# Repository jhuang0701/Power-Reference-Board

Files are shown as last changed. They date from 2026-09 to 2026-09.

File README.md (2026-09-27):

# 3-Phase FOC BLDC Motor Driver with Onboard IMU

A custom 4-layer PCB for field-oriented control (FOC) of a brushless DC motor, with an onboard IMU for real-time orientation feedback. Designed in KiCad, targeting a self-balancing single-wheel robot or reaction-wheel inverted pendulum as the demo application.

This is a design-only project: schematic and layout are complete and DRC-clean. Fabrication is a separate decision, not yet made.

## What it does

The board takes a 6S battery input (22.2V nominal, up to 25.2V) and drives a 3-phase BLDC motor using field-oriented control, with current feedback and IMU data available for a real-time stabilization loop. It's built around three main subsystems: power delivery and protection, the 3-phase gate drive and half-bridge power stage, and the sensing/control electronics.

## Core components

- **MCU:** STM32G474RET6 (LQFP-64). Chosen specifically for its onboard op-amps, which are used directly for current-sense amplification, and for TIM1's hardware dead-time generation on complementary PWM channels.
- **Gate driver:** DRV8353HRTAT, a 102V-rated 3-phase smart gate driver in hardware-interface mode (no SPI on this variant), configured via resistor-divider pins for 6x independent PWM mode.
- **Phase MOSFETs:** 6x CSD18540Q5BT (60V, 2.2mΩ RDS(on)), two per phase leg.
- **IMU:** ICM-42688-P, 6-axis accelerometer/gyroscope, connected over SPI.
- **Buck converter:** TPS54331DR, steps the battery rail down to a clean 3.3V supply for the MCU and IMU.
- **Reverse-polarity protection:** a 7th CSD18540Q5BT, wired low-side in the ground return path, with a Zener-clamped gate bias network. (An earlier design used a small P-channel MOSFET for this; it was replaced after checking its actual gate-voltage rating against the battery voltage and finding it wouldn't survive.)

## Design decisions worth knowing about

**Dual current-sensing paths.** The DRV8353HRTAT's built-in shunt amplifiers are used only for the driver's own hardware overcurrent protection, independent of the MCU. The actual current feedback used for the FOC control loop comes from the STM32G474's internal op-amps, wired directly to the same shunt resistors. Two separate paths, one fast and hardware-only for protection, one precise and MCU-driven for control.

**Hardware dead-time via TIM1.** Rather than relying on the gate driver's default switching behavior, all six gate signals (INHx/INLx) are driven independently from the MCU's TIM1 timer, which generates dead-time insertion in hardware. This gives direct control over switching behavior rather than trusting a fixed driver-side default.

**Mixed-signal supply isolation.** VDDA (the MCU's analog supply, feeding the ADC and current-sense op-amps) is isolated from the main 3.3V digital rail with a series resistor and its own local decoupling, keeping switching noise out of the current measurements.

## Specs

| | |
|---|---|
| Input | 6S Li-ion, 22.2V nominal / 25.2V max |
| Phase current | 15A continuous, 30A peak |
| Board | 4-layer, 60x60mm, 2oz outer copper |
| MCU | STM32G474RET6 |
| Gate driver | DRV8353HRTAT |
| IMU | ICM-42688-P (SPI) |

## Repo contents

- `/schematic` - full schematic PDF export
- `/gerbers` - fabrication-ready Gerber files
- `/bom` - bill of materials
- `/renders` - 3D board renders and layout screenshots

## Status

Schematic and layout complete, DRC-clean. Fabrication not yet started.

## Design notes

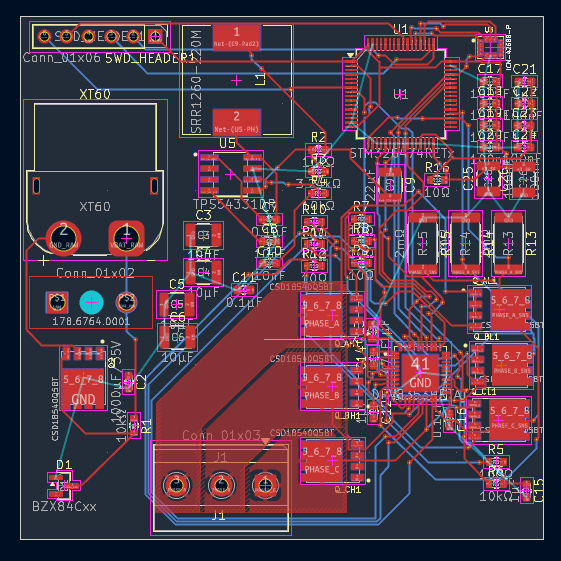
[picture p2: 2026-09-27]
public/project-power-reference-board-2d-view.png

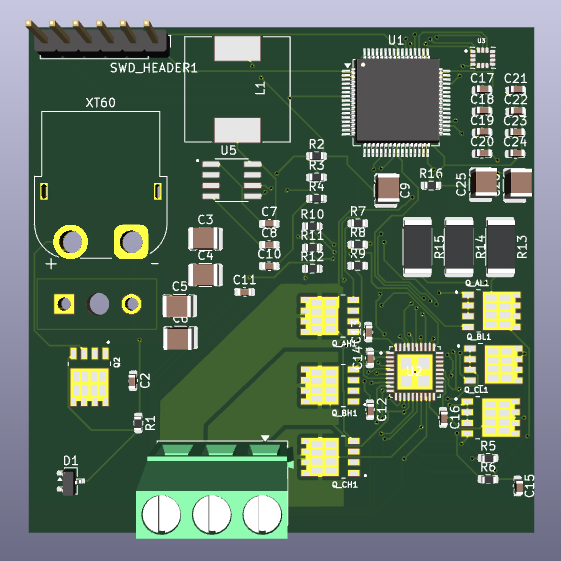
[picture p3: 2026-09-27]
public/project-power-reference-board-3d-view-front.png

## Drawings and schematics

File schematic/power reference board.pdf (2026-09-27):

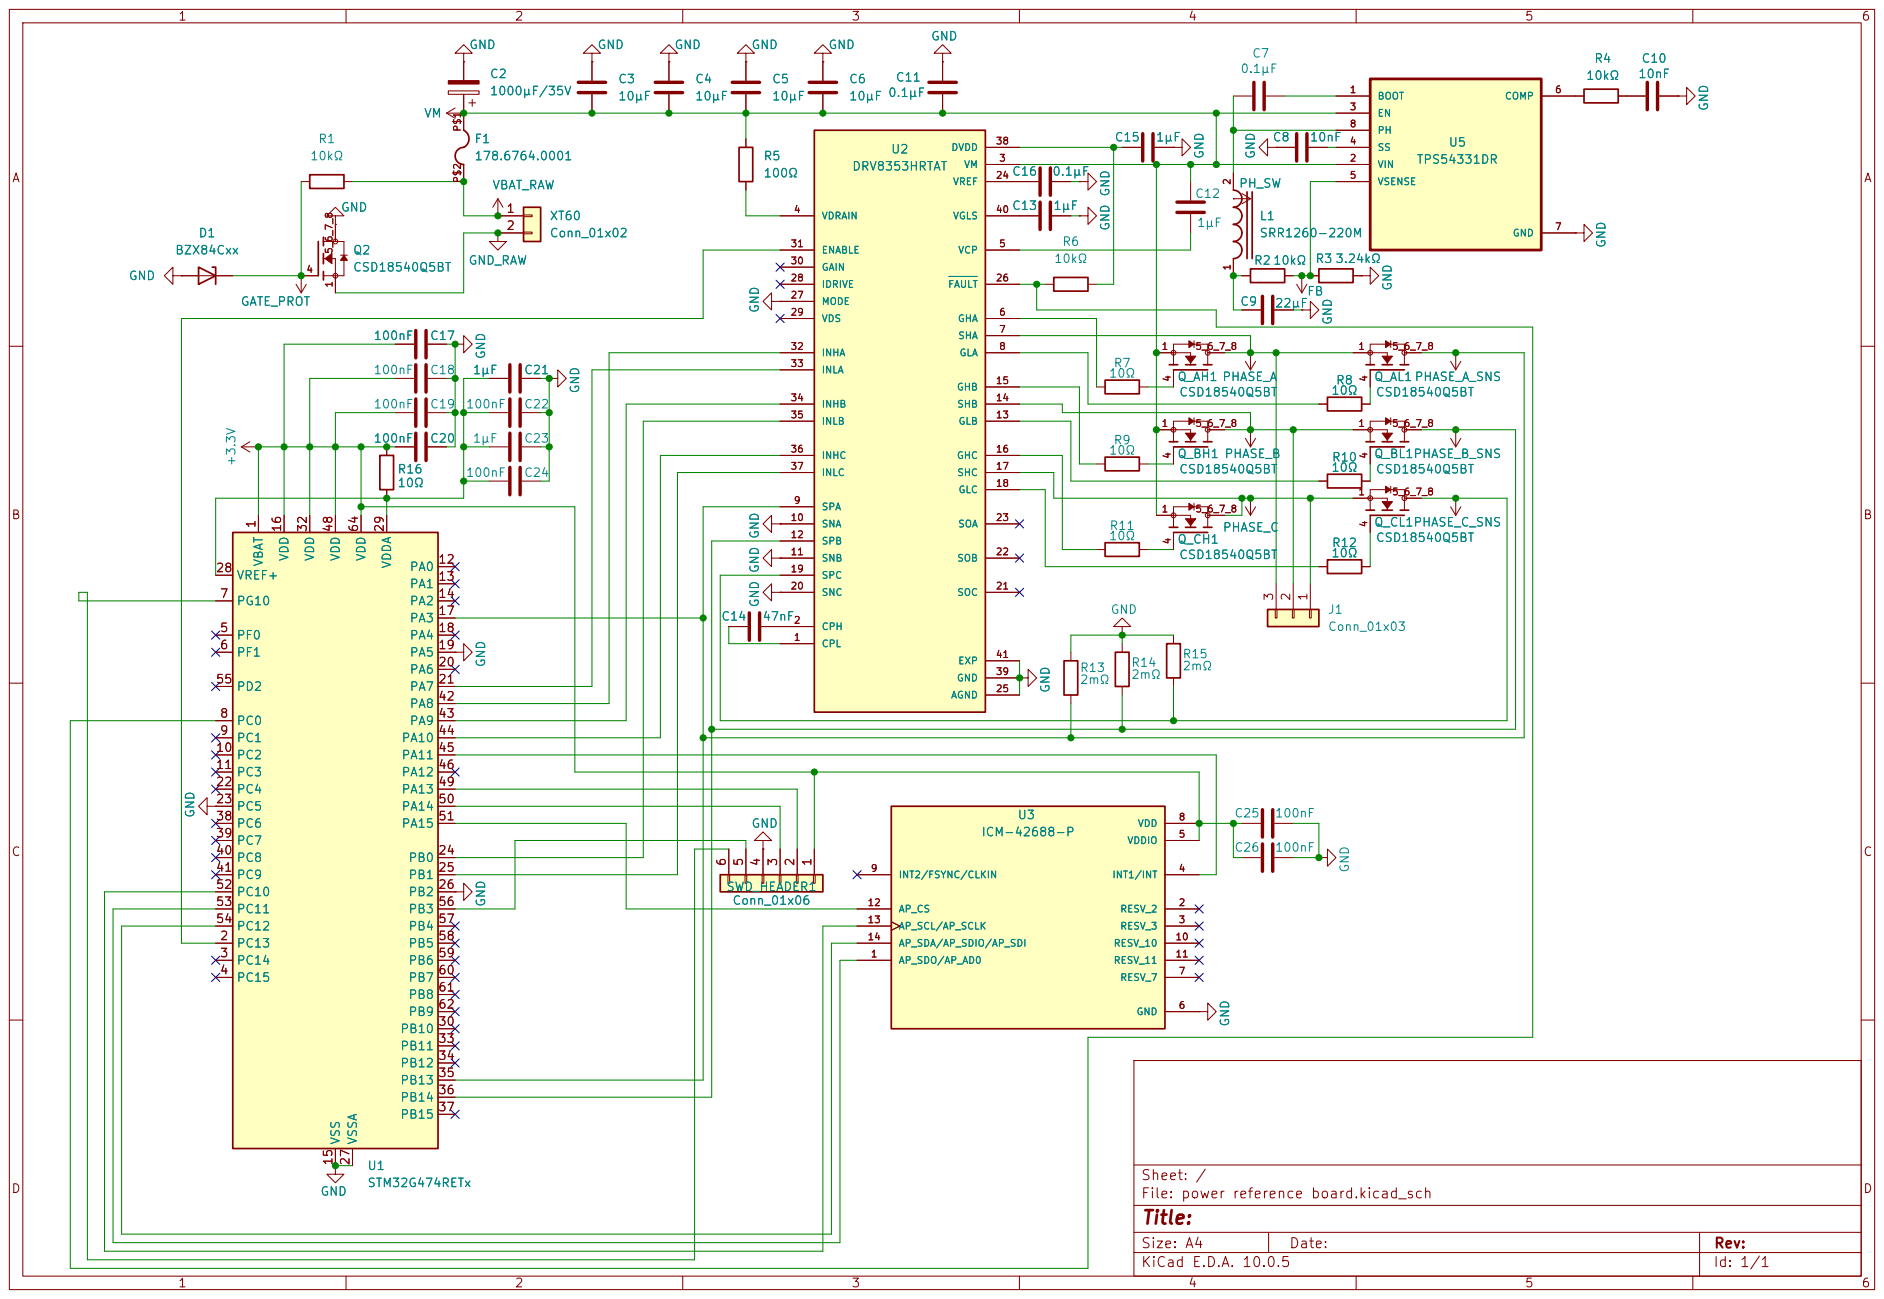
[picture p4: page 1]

Sheet: /
File: power reference board.kicad_sch
Title:

Size: A4 | Rev:
KiCad E.D.A. 10.0.5 | Id: 1/1

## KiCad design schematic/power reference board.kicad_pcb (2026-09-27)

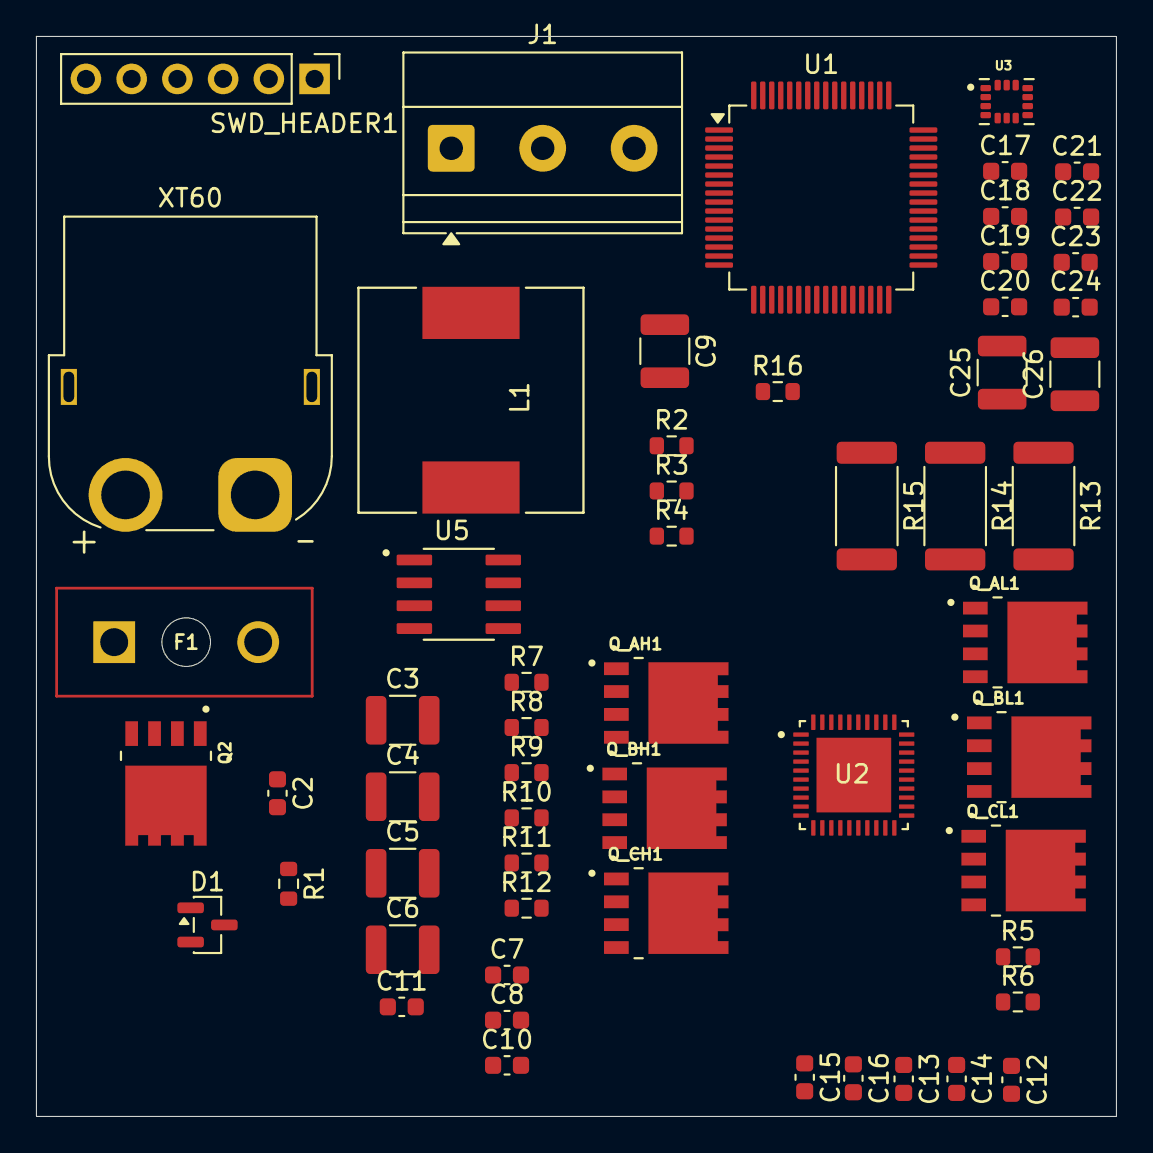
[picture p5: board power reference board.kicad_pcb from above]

Board: 4 copper layers, 60.0 x 60.0 mm, 58 parts (0 on the bottom side), 56 nets, no tracks yet.

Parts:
C2: 1000µF/35V; C_0603_1608Metric
C3, C4, C5, C6: 10µF; C_1210_3225Metric
C7, C11, C16: 0.1µF; C_0603_1608Metric
C8, C10: 10nF; C_0603_1608Metric
C9: 22µF; C_1210_3225Metric
C12, C13, C15, C21, C23: 1µF; C_0603_1608Metric
C14: 47nF; C_0603_1608Metric
C17, C18, C19, C20, C22, C24: 100nF; C_0603_1608Metric
C25, C26: 100nF; C_1210_3225Metric
D1: BZX84Cxx; SOT-23
F1: 178.6764.0001; LITTLEFUSE_178.6764.0001
J1: Conn_01x03; TerminalBlock_Phoenix_MKDS-1,5-3-5.08_1x03_P5.08mm_Horizont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
L1: SRR1260-220M; INDP125125X600N
Q2: CSD18540Q5BT; TRANS_CSD18540Q5BT
Q_AH1: CSD18540Q5BT; TRANS_CSD18540Q5BT
Q_AL1: CSD18540Q5BT; TRANS_CSD18540Q5BT
Q_BH1: CSD18540Q5BT; TRANS_CSD18540Q5BT
Q_BL1: CSD18540Q5BT; TRANS_CSD18540Q5BT
Q_CH1: CSD18540Q5BT; TRANS_CSD18540Q5BT
Q_CL1: CSD18540Q5BT; TRANS_CSD18540Q5BT
R1, R2, R4, R6: 10kΩ; R_0603_1608Metric
R3: 3.24kΩ; R_0603_1608Metric
R5: 100Ω; R_0603_1608Metric
R7, R8, R9, R10, R11, R12, R16: 10Ω; R_0603_1608Metric
R13, R14, R15: 2mΩ; R_2512_6332Metric
SWD_HEADER1: Conn_01x06; PinHeader_1x06_P2.54mm_Vertical
U1: STM32G474RETx; LQFP-64_10x10mm_P0.5mm
U2: DRV8353HRTAT; QFN50P600X600X80-41N
U3: ICM-42688-P; PQFN50P300X250X97-14N
U5: TPS54331DR; SOIC127P599X175-8N
XT60: Conn_01x02; AMASS_XT60PW-F_1x02_P7.20mm_Horizontal

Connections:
+3.3V: C17.2, C18.2, C19.2, C20.2, C25.2, C26.2, R16.2, SWD_HEADER1.1, U1.1 (VBAT), U1.16 (VDD), U1.32 (VDD), U1.48 (VDD), U1.64 (VDD), U3.5 (VDDIO), U3.8 (VDD)
FB: R2.1, R3.2, U5.5 (VSENSE)
GATE_PROT: D1.3 (K), Q2.4, R1.2
GND: C2.2, C3.1, C4.1, C5.1, C6.1, C8.2, C9.1, C10.1, C11.1, C13.2, C15.2, C16.2, C17.1, C18.1, C19.1, C20.1, C21.1, C22.1, C23.1, C24.1, C25.1, C26.1, D1.1 (A), Q2.5_6_7_8, R3.1, R13.1, R14.1, R15.1, SWD_HEADER1.4, U1.15 (VSS), U1.19 (PA5), U1.23 (PC5), U1.26 (PB2), U1.27 (VSSA), U1.31 (VSS), U1.47 (VSS), U1.63 (VSS), U2.10 (SNA), U2.11 (SNB), U2.20 (SNC), U2.25 (AGND), U2.27 (MODE), U2.39 (GND), U2.41 (EXP), U3.6 (GND), U5.7 (GND)
GND_RAW: Q2.1, Q2.2, Q2.3, XT60.2
unnamed: C9.2, L1.1, R2.2
unnamed: C10.2, R4.1
unnamed: Q_AH1.4, R7.1
unnamed: Q_AL1.4, R8.1
unnamed: Q_BH1.4, R9.1
unnamed: Q_BL1.4, R10.1
unnamed: Q_CH1.4, R11.1
unnamed: Q_CL1.4, R12.1
unnamed: SWD_HEADER1.2, U1.49 (PA13)
unnamed: SWD_HEADER1.3, U1.50 (PA14)
unnamed: SWD_HEADER1.5, U1.56 (PB3)
unnamed: SWD_HEADER1.6, U1.7 (PG10)
unnamed: U1.21 (PA7), U2.33 (INLA)
unnamed: U1.42 (PA8), U2.32 (INHA)
unnamed: U1.43 (PA9), U2.34 (INHB)
unnamed: U1.44 (PA10), U2.36 (INHC)
unnamed: U1.45 (PA11), U3.4 (INT1/INT)
unnamed: U1.51 (PA15), U3.12 (AP_CS)
unnamed: U1.24 (PB0), U2.35 (INLB)
unnamed: U1.25 (PB1), U2.37 (INLC)
unnamed: R6.1, U1.8 (PC0), U2.26 (~FAULT)
unnamed: U1.52 (PC10), U3.13 (AP_SCL/AP_SCLK)
unnamed: U1.53 (PC11), U3.1 (AP_SDO/AP_AD0)
unnamed: U1.54 (PC12), U3.14 (AP_SDA/AP_SDIO/AP_SDI)
unnamed: U1.2 (PC13), U2.31 (ENABLE)
unnamed: C21.2, C22.2, C23.2, C24.2, R16.1, U1.28 (VREF+), U1.29 (VDDA)
unnamed: C14.1, U2.2 (CPH)
unnamed: C14.2, U2.1 (CPL)
unnamed: C15.1, R6.2, U2.38 (DVDD)
unnamed: R7.2, U2.6 (GHA)
unnamed: R9.2, U2.15 (GHB)
unnamed: R11.2, U2.16 (GHC)
unnamed: R8.2, U2.8 (GLA)
unnamed: R10.2, U2.13 (GLB)
unnamed: R12.2, U2.18 (GLC)
unnamed: C12.1, U2.5 (VCP)
unnamed: R5.1, U2.4 (VDRAIN)
unnamed: C13.1, U2.40 (VGLS)
unnamed: C16.1, U2.24 (VREF)
unnamed: C7.1, U5.1 (BOOT)
unnamed: R4.2, U5.6 (COMP)
unnamed: C7.2, L1.2, U5.8 (PH)
unnamed: C8.1, U5.4 (SS)
PHASE_A: J1.3, Q_AH1.5_6_7_8, Q_AL1.1, Q_AL1.2, Q_AL1.3, U2.7 (SHA)
PHASE_A_SNS: Q_AL1.5_6_7_8, R13.2, U1.17 (PA3), U1.35 (PB13), U2.9 (SPA)
PHASE_B: J1.2, Q_BH1.5_6_7_8, Q_BL1.1, Q_BL1.2, Q_BL1.3, U2.14 (SHB)
PHASE_B_SNS: Q_BL1.5_6_7_8, R14.2, U1.36 (PB14), U2.12 (SPB)
PHASE_C: J1.1, Q_CH1.5_6_7_8, Q_CL1.1, Q_CL1.2, Q_CL1.3, U2.17 (SHC)
PHASE_C_SNS: Q_CL1.5_6_7_8, R15.2, U2.19 (SPC)
VBAT_RAW: F1.P$2, R1.1, XT60.1
VM: C2.1, C3.2, C4.2, C5.2, C6.2, C11.2, C12.2, F1.P$1, Q_AH1.1, Q_AH1.2, Q_AH1.3, Q_BH1.1, Q_BH1.2, Q_BH1.3, Q_CH1.1, Q_CH1.2, Q_CH1.3, R5.2, U2.3 (VM), U5.2 (VIN), U5.3 (EN)

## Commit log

2026-09-27 Organize board files into project folders
    [power reference board-B_Cu.gbr, power reference board-B_Mask.gbr, power reference board-B_Paste.gbr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]
2026-09-27 Add board screenshots
2026-09-27 Rename board screenshots
2026-09-28 Rename board view images and remove empty render folder
